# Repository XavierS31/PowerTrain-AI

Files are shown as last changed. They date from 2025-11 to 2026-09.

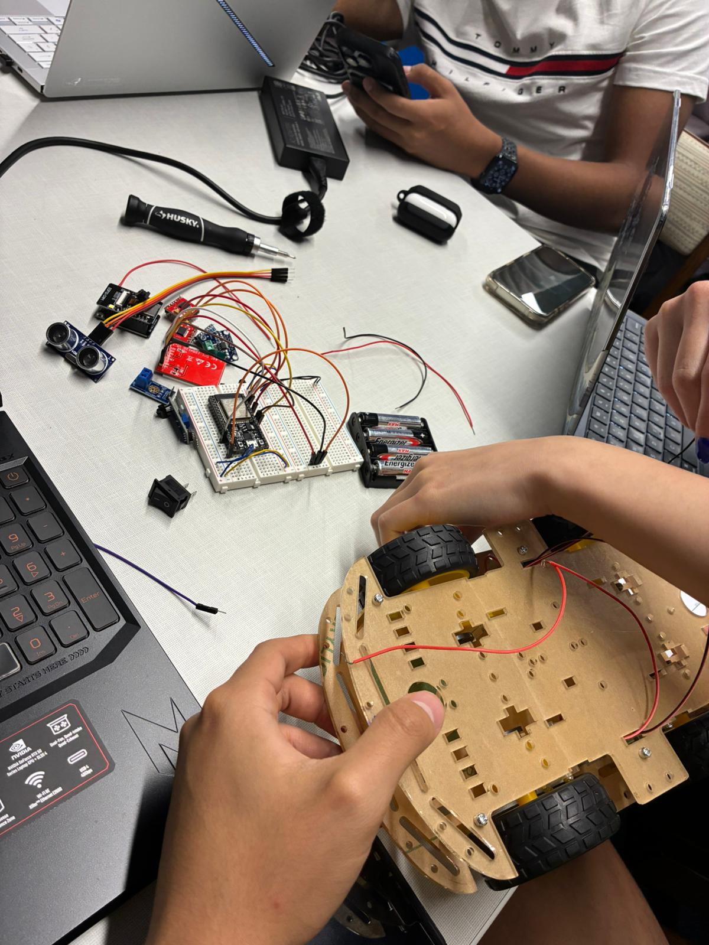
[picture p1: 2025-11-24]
images/buildingBeginning.jpg

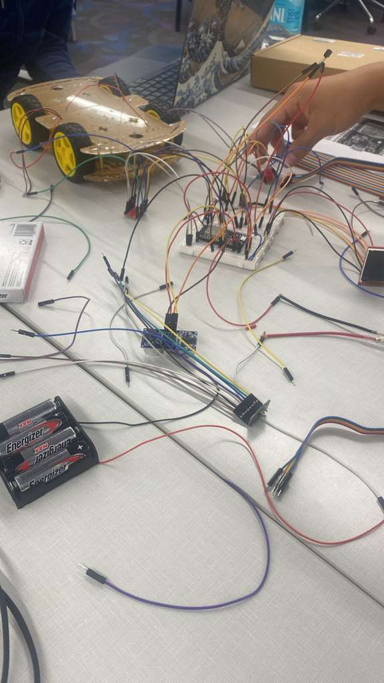
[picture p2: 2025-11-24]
images/circuitBuilding.jpg

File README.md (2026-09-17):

# ⚡ PowerTrain AI

PowerTrain AI is a comprehensive autonomous car system powered by ESP32, featuring real-time sensor data collection, machine learning-based performance prediction, and intelligent autonomous driving capabilities. The system integrates embedded hardware, Python-based ML models, and RESTful APIs to create a complete end-to-end solution for autonomous vehicle control and battery health monitoring.

## 🚀 Overview

PowerTrain AI combines embedded systems engineering with machine learning to create an intelligent autonomous car that adapts its driving behavior based on real-time performance predictions. The system collects sensor data from multiple sources (temperature, voltage, current, acceleration, distance), processes it through ML models which are later tested, and uses predictions to optimize autonomous driving decisions in real-time.

The project consists of three main components:
- **Embedded System**: ESP32-based car with sensor integration and autonomous driving logic
- **Machine Learning**: Tested Three ML models (PyTorch Neural Network, scikit-learn MLP, Random Forest Algortihm) for performance prediction and pick the best results.
- **Data Infrastructure**: Flask servers for data collection, ML predictions, and database management

## ⚙️ Features

### 🚗 Autonomous Driving

- **Basic Autonomous Mode**: Obstacle avoidance using ultrasonic (HC-SR04) and infrared sensors
- **ML-Enhanced Autonomous Mode**: Performance-based speed and behavior adjustment using real-time ML predictions
- **Three Speed Levels**: Low (85 PWM), Medium (170 PWM), High (255 PWM) with smooth acceleration/deceleration
- **Intelligent Navigation**: Left/right path selection based on obstacle detection and distance scanning
- **Emergency Stop**: Immediate stop on critical obstacle detection

### 📊 Sensor Data Collection

- **Temperature Monitoring**: DS18B20 digital temperature sensor (OneWire protocol)
- **Voltage Detection**: 0-25V voltage sensor module (GPIO 34 ADC)
- **Current/Power Measurement**: INA219 I2C sensor for precise current and power readings
- **Accelerometer/Gyroscope**: MPU6050 6-axis IMU (I2C) for acceleration and orientation
- **Distance Sensing**: HC-SR04 ultrasonic sensor (GPIO 17/16) for obstacle detection
- **Infrared Obstacle Detection**: TCRT5000 IR sensor (GPIO 36/39) for close-range detection
- **Speed Measurement**: Encoder-based speed calculation from motor rotations

### 🧠 Machine Learning Models Tested

#### PyTorch Neural Network
- **Architecture**: 2 hidden layers with 16 neurons each
- **Activation**: ReLU with Dropout (0.2) for regularization
- **Framework**: PyTorch
- **Output**: Performance level classification (1-10)
- **Saved as**: `pytorch_nn_model.pth`

#### scikit-learn MLP (Multi-Layer Perceptron)
- **Architecture**: 2 hidden layers (16, 8 neurons)
- **Framework**: scikit-learn
- **Solver**: Adam optimizer
- **Output**: Performance level classification (1-10)
- **Saved as**: `mlp_model.py`

#### Random Forest Classifier
- **Parameters**: 100 decision trees, max depth 20
- **Framework**: scikit-learn
- **Features**: Feature importance analysis
- **Output**: Performance level classification (1-10)
- **Saved as**: `random_forest_model.py`

### 📡 Data Infrastructure

- **Data Receiver API**: Flask server receiving sensor data from ESP32 via WiFi
- **ML Prediction API**: Real-time performance predictions from trained models
- **Data Query API**: RESTful API for querying SQLite database
- **Multiple Data Formats**: JSON, CSV, SQLite, Parquet, HDF5, Excel support
- **SQLite Database**: Structured storage for driving behavior data with indexes

### 🖥️ TFT Display

- **ST7735S Display**: 1.8" TFT screen showing real-time performance metrics
- **Performance Percentage**: Calculated from internal resistance, temperature, and current
- **Visual Feedback**: Color-coded performance indicators

## 🧑‍💻 Tech Stack

| Layer | Technologies |
|---|---|
| **Embedded** | ESP32 DevKit V1, Arduino Framework, PlatformIO, C++, C|
| **Sensors** | DS18B20, INA219, MPU6050, HC-SR04, TCRT5000, Voltage Sensor |
| **Actuators** | TB6612FNG Motor Driver, ST7735S TFT Display |
| **Communication** | WiFi (HTTP), Bluetooth (optional), Serial (115200 baud) |
| **Backend** | Python, Flask, SQLite |
| **Machine Learning** | PyTorch, scikit-learn, NumPy, Pandas, Matplotlib |
| **Data Processing** | Pandas, NumPy, StandardScaler |
| **Visualization** | Matplotlib, Seaborn |
| **Development** | PlatformIO, Arduino IDE compatible |

## 🛠️ Setup Instructions

### Prerequisites

- **Python** (for ML models and data servers)
- **Node.js** (optional, for some utilities)
- **PlatformIO** or **Arduino IDE** (for ESP32 development)
- **ESP32 DevKit V1** connected via USB
- **Git**

### 1. Clone the Repository

```bash
git clone https://github.com/XavierS31/PowerTrain-AI.git
cd PowerTrain-AI
```

### 2. Python Environment Setup

```bash
# Install Python dependencies
cd Software
pip install -r requirements.txt
```

Required packages:
- `pandas`, `numpy`, `scikit-learn`, `torch` (PyTorch)
- `flask`, `flask-cors`, `python-dotenv`
- `matplotlib`, `seaborn`, `joblib`
- `sqlite3` (built-in)

### 3. Database Setup

```bash
cd Software/src
python create_database.py
```

This creates:
- SQLite database at `Software/data/database/driving_behavior.db`
- Schema with indexes for performance
- Imports data from `driving_behavior_dataset.csv` (if available)

### 4. Train Machine Learning Models

Train all three models at once:

```bash
cd Software/src
python save_model.py
```

Or train individually:

```bash
# PyTorch Neural Network
python train_pytorch_nn.py

# scikit-learn MLP
python train_mlp.py

# Random Forest
python train_random_forest.py
```

Models are saved to `Software/models/`:
- `pytorch_nn_model.pth` + `pytorch_scaler.joblib`
- `mlp_model.joblib` + `scaler.joblib`
- `random_forest_model.joblib` + `random_forest_scaler.joblib`

### 5. Evaluate Models

Compare all trained models:

```bash
cd Software/src
python evaluate_models.py
```

Generates:
- Confusion matrices for each model
- Model comparison plots
- Comprehensive evaluation report with accuracy, precision, recall, F1-score

### 6. Configure ESP32

Edit `Embedded/src/config/config.h`:

```cpp
#define WIFI_SSID "YOUR_WIFI_SSID"
#define WIFI_PASSWORD "YOUR_WIFI_PASSWORD"
#define SERVER_IP "OUR_IP"  // Your computer's IP
#define SERVER_PORT 5000
```

Or use the template: `Embedded/src/config/config.h.template`

### 7. Compile and Upload to ESP32

#### Option A: Using Batch Script (Windows)

```bash
cd Embedded
compile_and_upload_autonomous.bat
```

This script:
1. Compiles code with PlatformIO
2. Prompts for ESP32 upload
3. Handles download mode instructions

**If upload fails:**
1. Hold the **BOOT** button
2. Press and release **RESET** button
3. Release **BOOT** button
4. Try upload again

#### Option B: Using PlatformIO CLI

```bash
cd Embedded
pio run              # Compile
pio run -t upload    # Upload
pio device monitor    # Serial monitor
```

#### Option C: Using Arduino IDE

1. Open `Embedded/autonomous_Driving/autonomous_Driving.ino` in Arduino IDE
2. Install ESP32 board support (ESP32 Dev Module)
3. Install required libraries:
   - NewPing
   - Encoder
   - OneWire
   - DallasTemperature
   - Adafruit INA219
   - Adafruit MPU6050
   - Adafruit ST7735
   - Adafruit GFX
4. Select board: **ESP32 Dev Module**
5. Select port: **COM4** (or your port)
6. Upload

### 8. Start Data Receiver Server

```bash
cd Software/data
python data_receiver.py
```

Server runs on `http://0.0.0.0:5000` (configurable via `.env`)

Endpoints:
- `POST /api/data` - Receive sensor data from ESP32
- `POST /api/predict` - Get ML prediction for sensor data
- `GET /api/status` - Check server and model status

### 9. Start Data Query API (Optional)

```bash
cd Software/data
python data_api.py
```

API runs on `http://0.0.0.0:5001` (configurable via `DATA_API_PORT` in `.env`)

Endpoints:
- `GET /api/data/records` - Query driving behavior records
- `GET /api/data/stats` - Statistical summary
- `GET /api/data/levels` - Level distribution
- `GET /api/data/record/<id>` - Get specific record
- `GET /api/data/export` - Export as CSV
- `GET /api/data/status` - API health check

## 📡 API Documentation

### Data Receiver API (Port 5000)

#### POST /api/data
Receive sensor data from ESP32 and save to database.

**Request Body:**
```json
{
  "temperature": 25.5,
  "voltage": 12.3,
  "current": 1.2,
  "power": 14.76,
  "accelX": 0.1,
  "accelY": 0.2,
  "accelZ": 9.8,
  "gyroX": 0.0,
  "gyroY": 0.0,
  "gyroZ": 0.0,
  "distance": 45.0,
  "speed": 0.5,
  "irDigital": 0,
  "irAnalog": 512
}
```

**Response:**
```json
{
  "status": "success",
  "message": "Data saved"
}
```

#### POST /api/predict
Get ML prediction for sensor data.

**Request Body:**
```json
{
  "voltage": 12.3,
  "current": 1.2,
  "temperature": 25.5,
  "accelX": 0.1,
  "accelY": 0.2,
  "accelZ": 9.8,
  "speed": 0.5,
  "distance": 45.0
}
```

**Response:**
```json
{
  "status": "success",
  "predicted_level": 7,
  "confidence": 0.92
}
```

#### GET /api/status
Check server and model status.

**Response:**
```json
{
  "status": "running",
  "model_loaded": true,
  "scaler_loaded": true
}
```

### Data Query API (Port 5001)

#### GET /api/data/records
Query driving behavior records with filtering.

**Query Parameters:**
- `limit` (default: 100) - Number of records
- `offset` (default: 0) - Pagination offset
- `level` - Filter by performance level (1-10)
- `min_voltage` - Minimum voltage filter
- `max_voltage` - Maximum voltage filter

**Example:**
```
GET /api/data/records?limit=50&level=7&min_voltage=12.0
```

#### GET /api/data/stats
Get statistical summary of database.

**Response:**
```json
{
  "total_records": 1000,
  "levels": {
    "1": 50,
    "2": 75,
    ...
  },
  "avg_voltage": 12.3,
  "avg_current": 1.2
}
```

## 📁 Project Structure

```
PowerTrain AI/
├── Embedded/                          # ESP32 firmware
│   ├── src/
│   │   ├── main.cpp                  # Main program entry point
│   │   ├── ESP32_car.h               # Core library includes
│   │   ├── config/
│   │   │   ├── config.h             # Configuration (WiFi, pins, speeds)
│   │   │   └── config.h.template    # Configuration template
│   │   ├── sensors/
│   │   │   ├── DS18B20_temp.cpp     # Temperature sensor driver
│   │   │   ├── HC-SRO4_Infrared.cpp # Ultrasonic distance sensor
│   │   │   ├── I2C_BUS.cpp          # I2C bus initialization
│   │   │   ├── IR_MH_Sensor.cpp     # Infrared obstacle sensor
│   │   │   ├── TB6612FNG_MotorStepper.cpp  # Motor driver
│   │   │   ├── TFT_LED.cpp          # TFT display functions
│   │   │   ├── TFT_LED.h            # TFT display header
│   │   │   └── voltage_sensor.cpp   # Voltage detection
│   │   ├── autonomous_drive.h       # Basic autonomous driving header
│   │   ├── autonomous_drive_ml.h    # ML-enhanced driving header
│   │   ├── autonomous_drive_ml.cpp  # ML-enhanced driving implementation
│   │   ├── ml_predictor.h           # ML prediction API header
│   │   └── ml_predictor.cpp         # HTTP client for ML predictions
│   ├── autonomous_Driving/
│   │   └── autonomous_Driving.ino   # Standalone autonomous sketch
│   ├── bluetooth_Driving/
│   │   └── bluetooth_Driving.ino    # Bluetooth control sketch
│   ├── compile_and_upload_autonomous.bat  # Build and upload script
│   └── platformio.ini               # PlatformIO configuration
│
├── Software/                         # Python ML and data processing
│   ├── data/
│   │   ├── raw_data/                # Raw sensor data from ESP32
│   │   │   └── *.jsonl, *.csv, *.db, *.parquet, *.h5, *.xlsx
│   │   ├── database/
│   │   │   └── driving_behavior.db   # SQLite database
│   │   ├── data_receiver.py         # Flask server for data reception
│   │   ├── data_api.py              # RESTful API for data queries
│   │   ├── check_security.py        # Security scanner
│   │   ├── SECURITY.md              # Security guidelines
│   │   ├── driving_behavior_dataset.csv  # Training dataset
│   │   └── data.pdf                 # Data documentation
│   ├── models/                      # Trained ML models
│   │   ├── mlp_model.joblib        # scikit-learn MLP model
│   │   ├── scaler.joblib           # Feature scaler for MLP
│   │   ├── random_forest_model.joblib
│   │   ├── random_forest_scaler.joblib
│   │   ├── pytorch_nn_model.pth    # PyTorch neural network
│   │   ├── pytorch_scaler.joblib
│   │   └── results/                # Evaluation plots and reports
│   ├── src/
│   │   ├── create_database.py      # Create SQLite database from CSV
│   │   ├── preprocessing.py          # Process raw data for ML
│   │   ├── save_model.py            # Train and save all three models
│   │   ├── train_pytorch_nn.py      # Train PyTorch neural network
│   │   ├── train_random_forest.py   # Train Random Forest
│   │   ├── train_mlp.py            # Train scikit-learn MLP
│   │   ├── evaluate_models.py       # Evaluate all models
│   │   └── model.py                # Original MLP training script
│   ├── requirements.txt             # Python dependencies
│   └── README.md                    # Software module documentation
│
├── scripts/                         # Utility scripts
│   ├── install_platformio.ps1      # PlatformIO installation (Windows)
│   └── install_platformio.sh       # PlatformIO installation (Linux/Mac)
│
├── images/                          # Project images
│   ├── car.jpg
│   ├── carSideways.jpg
│   ├── carTraining.jpg
│   ├── buildingBeginning.jpg
│   └── circuitBuilding.jpg
│
├── Modelling/                       # 3D models
│   ├── base_modelling_final.SLDPRT
│   ├── base_modelling_intial.SLDPRT
│   └── solidworks_Final.jpg
│
├── Schematics/                      # Circuit schematics
│   ├── Schematics.jpg
│   └── Schematics_start.jpg
│
├── run_model.bat                    # Run ML model training
├── .gitignore                       # Git ignore rules
├── PLATFORMIO_SETUP.md              # PlatformIO setup guide
└── README.md                        # This file
```

## 🔄 Data Flow

### Training Phase

1. **Data Collection**: ESP32 collects sensor data during autonomous driving
2. **Data Transmission**: Sensor data sent via WiFi to Flask server (`data_receiver.py`)
3. **Data Storage**: Data saved in multiple formats (CSV, JSON, SQLite, etc.)
4. **Data Preprocessing**: `preprocessing.py` calculates derived features:
   - Internal resistance (from voltage drop and current)
   - Combined acceleration magnitude
   - Cumulative distance
   - Performance level assignment (1-10)
5. **Database Import**: `create_database.py` imports processed data to SQLite
6. **Model Training**: `save_model.py` trains all three models:
   - Features: InternalResistance, StartingInternalResistance, Voltage, Current, Temp, AccelX, AccelY, AccelCombined, Speed, Distance
   - Target: Level (1-10 performance classification)
   - Train-test split: 80-20 with stratification
   - Feature scaling: StandardScaler
7. **Model Evaluation**: `evaluate_models.py` compares all models and generates reports

### Inference Phase (Real-Time)

1. **Sensor Reading**: ESP32 reads all sensors (temperature, voltage, current, acceleration, distance, speed)
2. **Data Preprocessing**: ESP32 calculates internal resistance and combined acceleration
3. **HTTP Request**: ESP32 sends sensor data to `/api/predict` endpoint
4. **ML Prediction**: Python server:
   - Loads trained model and scaler
   - Preprocesses input data
   - Makes prediction (level 1-10)
   - Returns prediction and confidence
5. **Autonomous Decision**: ESP32 uses prediction to:
   - Adjust speed based on performance level
   - Modify obstacle detection thresholds
   - Optimize driving behavior

## 🎯 Autonomous Driving Modes

### Basic Autonomous Mode

Uses sensor-based obstacle avoidance:
- Forward movement with continuous distance monitoring
- Turn left/right based on clearer path detection
- Backup and turn when completely blocked
- Speed control via Serial commands (L/M/H/S)

### ML-Enhanced Autonomous Mode

Integrates ML predictions for intelligent behavior:
- **Performance-Based Speed**: Adjusts speed based on predicted performance level
  - Level 1-3: Low speed (conservative)
  - Level 4-7: Medium speed (balanced)
  - Level 8-10: High speed (aggressive)
- **Adaptive Thresholds**: Obstacle detection thresholds adjust based on confidence
- **Predictive Behavior**: Anticipates performance degradation and adjusts proactively

## 📊 Model Training Results

All models are trained on the same dataset with:
- **Features**: 10 input features (InternalResistance, Voltage, Current, Temp, AccelX, AccelY, AccelCombined, Speed, Distance, StartingInternalResistance)
- **Target**: Performance level (1-10 classification)
- **Train-Test Split**: 80-20 with stratification
- **Evaluation Metrics**: Accuracy, Precision, Recall, F1-Score, Confusion Matrix

Run `evaluate_models.py` to see detailed results for each model.

## 🚀 Running Batch Scripts

### run_model.bat

Trains the MLP model and generates visualization:

```bash
run_model.bat
```

This script:
1. Checks Python installation
2. Installs required packages
3. Runs `train_mlp.py`
4. Generates confusion matrix visualization
5. Saves results to `Software/models/results/`

### compile_and_upload_autonomous.bat

Compiles and uploads autonomous driving code to ESP32:

```bash
cd Embedded
compile_and_upload_autonomous.bat
```

This script:
1. Compiles code with PlatformIO
2. Prompts for ESP32 upload
3. Provides instructions for download mode if needed

**Note**: Make sure ESP32 is connected to COM4 (or update `platformio.ini` with your port).

## 🔧 Troubleshooting

### ESP32 Upload Issues

**Problem**: Upload fails with "Wrong boot mode detected"

**Solution**:
1. Hold the **BOOT** button
2. Press and release **RESET** button
3. Release **BOOT** button
4. Try upload again within 10 seconds

### WiFi Connection Issues

**Problem**: ESP32 cannot connect to WiFi

**Solution**:
1. Check WiFi credentials in `Embedded/src/config/config.h`
2. Verify WiFi network is 2.4GHz (ESP32 doesn't support 5GHz)
3. Check signal strength
4. Review Serial monitor for connection errors

### ML Predictions Not Working

**Problem**: ESP32 cannot get predictions from server

**Solution**:
1. Ensure `data_receiver.py` is running on port 5000
2. Check server IP in `config.h` matches your computer's IP
3. Verify models are loaded (check `/api/status` endpoint)
4. Check firewall settings allow port 5000

### Database Not Found

**Problem**: Models cannot find database

**Solution**:
```bash
cd Software/src
python create_database.py
```

### Model Training Errors

**Problem**: Training fails with missing data

**Solution**:
1. Ensure database exists: `Software/data/database/driving_behavior.db`
2. Verify database has data: Check with SQLite browser
3. Run `create_database.py` to import CSV data

### Sensor Reading Issues

**Problem**: Sensors not reading correctly

**Solution**:
1. Verify I2C connections (SDA=21, SCL=22)
2. Check sensor addresses with I2C scanner
3. Verify power supply (3.3V for sensors)
4. Check GPIO pin assignments in `config.h`

## Support

For questions, issues, or contributions:

- **Repository**: [PowerTrain AI](https://github.com/XavierS31/PowerTrain-AI)
- **Issues**: Open an issue on GitHub

## 🎯 Future Enhancements

- Real-time model retraining with new data
- Advanced sensor fusion algorithms
- Computer vision integration for object recognition
- GPS-based navigation and path planning
- Mobile app for remote monitoring and control
- Cloud deployment for ML inference
- Enhanced battery health prediction
- Multi-car fleet management
- Advanced obstacle avoidance with LiDAR
- Reinforcement learning for adaptive behavior

## 📝 License

This project is open source and available for educational and research purposes.

## 🙏 Acknowledgments

- ESP32 community for excellent documentation
- PlatformIO for seamless embedded development
- PyTorch and scikit-learn teams for ML frameworks
- Adafruit for sensor libraries and hardware

---

**Built with passion for autonomous systems and machine learning** ⚡🚗

**Resulted in first place for SHPE FALL 2025 Competitions**

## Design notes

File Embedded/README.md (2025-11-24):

# PowerTrain AI - Embedded Module

ESP32-based autonomous car with sensor integration and ML-powered performance prediction.

## Project Structure

```
Embedded/
├── src/
│   ├── main.cpp                    # Main program entry point
│   ├── ESP32_car.h                # Core library includes
│   ├── config/
│   │   └── config.h               # Configuration constants
│   ├── sensors/
│   │   ├── DS18B20_temp.cpp       # Temperature sensor
│   │   ├── HC-SRO4_Infrared.cpp   # Ultrasonic distance sensor
│   │   ├── I2C_BUS.cpp            # I2C bus initialization
│   │   ├── IR_MH_Sensor.cpp       # Infrared obstacle sensor
│   │   ├── TB6612FNG_MotorStepper.cpp  # Motor driver
│   │   ├── TFT_LED.cpp            # TFT display functions
│   │   ├── TFT_LED.h             # TFT display header
│   │   └── voltage_sensor.cpp    # Voltage detection
│   ├── autonomous_drive.h         # Autonomous driving header
│   ├── autonomous_drive_ml.h      # ML-enhanced driving header
│   ├── autonomous_drive_ml.cpp    # ML-enhanced driving implementation
│   ├── ml_predictor.h             # ML prediction API header
│   └── ml_predictor.cpp           # ML prediction API implementation
│
├── autonomous_Driving/
│   └── autonomous_Driving.ino     # Standalone autonomous driving sketch
│
├── bluetooth_Driving/
│   └── bluetooth_Driving.ino      # Bluetooth control sketch
│
├── compile_and_upload_autonomous.bat  # Build and upload script
└── platformio.ini                 # PlatformIO configuration
```

## Core Files

### Main Entry Point
- `src/main.cpp` - Main program loop, initializes sensors and runs autonomous driving

### Configuration
- `src/config/config.h` - Pin definitions, thresholds, timing constants

### Sensor Drivers
- `src/sensors/DS18B20_temp.cpp` - DS18B20 temperature sensor driver
- `src/sensors/HC-SRO4_Infrared.cpp` - HC-SR04 ultrasonic distance sensor
- `src/sensors/IR_MH_Sensor.cpp` - Infrared obstacle detection
- `src/sensors/voltage_sensor.cpp` - Battery voltage monitoring
- `src/sensors/TB6612FNG_MotorStepper.cpp` - Motor control driver
- `src/sensors/TFT_LED.cpp` - ST7735S TFT display driver
- `src/sensors/I2C_BUS.cpp` - I2C bus setup for sensors

### Autonomous Driving
- `src/autonomous_drive.h` - Basic autonomous driving interface
- `src/autonomous_drive_ml.h` - ML-enhanced autonomous driving interface
- `src/autonomous_drive_ml.cpp` - ML-enhanced driving with performance-based adjustments

### Machine Learning Integration
- `src/ml_predictor.h` - ML prediction API interface
- `src/ml_predictor.cpp` - HTTP client for Python ML server predictions

### Library Includes
- `src/ESP32_car.h` - Central header with all required library includes

## Compilation and Upload

### Using Batch Script

```bash
cd Embedded
compile_and_upload_autonomous.bat
```

This script:
1. Copies autonomous code to main.cpp
2. Compiles with PlatformIO
3. Prompts for ESP32 upload

### Using PlatformIO Directly

```bash
cd Embedded
pio run -t upload
```

## Hardware Configuration

### Sensors
- Temperature: DS18B20 (OneWire)
- Voltage: 0-25V detection module (GPIO 34)
- Current/Power: INA219 (I2C)
- Accelerometer/Gyro: MPU6050 (I2C)
- Distance: HC-SR04 (GPIO 17 trigger, GPIO 16 echo)
- Infrared: TCRT5000 (GPIO 36 digital, GPIO 39 analog)

### Actuators
- Motors: TB6612FNG driver (PWM control)
- Display: ST7735S TFT (SPI)

### Communication
- WiFi: For data transmission and ML predictions
- Serial: Debug output (115200 baud)

## Autonomous Driving Modes

### Basic Autonomous Mode
Uses obstacle avoidance with ultrasonic and IR sensors:
- Forward movement with obstacle detection
- Turn left/right based on clearer path
- Backup and turn when blocked

### ML-Enhanced Autonomous Mode
Integrates ML predictions to adjust behavior:
- Speed adjustment based on predicted performance level
- Obstacle threshold adaptation
- Confidence-based decision making

## ML Prediction Integration

The car can request performance predictions from the Python server:

```cpp
#include "src/ml_predictor.h"

SensorData data = readSensors();
MLPrediction pred = getMLPrediction(data, "http://SERVER_IP:5000");

if (pred.success) {
    // Use pred.level (1-10) and pred.confidence (0.0-1.0)
    adjustBehavior(pred);
}
```

## Key Functions

### Sensor Reading
- `readSensors()` - Read all sensor values
- `readDistance()` - Get ultrasonic distance
- `readIRSensor()` - Check IR obstacle detection
- `checkLeftDistance()` - Scan left side
- `checkRightDistance()` - Scan right side

### Motor Control
- `driveForward(speed)` - Move forward
- `turnLeft(speed)` - Turn left
- `turnRight(speed)` - Turn right
- `driveBackward(speed)` - Reverse
- `stopMotors()` - Stop all motors
- `emergencyStop()` - Immediate stop

### Autonomous Driving
- `autonomousDrive()` - Basic autonomous mode
- `autonomousDriveML()` - ML-enhanced autonomous mode
- `initAutonomousDrive()` - Initialize autonomous system
- `initAutonomousDriveML()` - Initialize ML-enhanced system

### ML Predictions
- `getMLPrediction(sensorData, serverURL)` - Get prediction from server
- `checkMLModelStatus(serverURL)` - Check if ML model is loaded

## Configuration

Edit `src/config/config.h` to adjust:
- Pin assignments
- Motor speeds
- Obstacle detection thresholds
- Sensor calibration values
- WiFi credentials
- Server URL

## Dependencies

PlatformIO libraries (defined in platformio.ini):
- OneWire
- DallasTemperature
- Adafruit INA219
- Adafruit MPU6050
- NewPing
- Adafruit ST7735
- Adafruit GFX
- Encoder
- ESP32AnalogRead
- ArduinoJson
- HTTPClient

## Development Workflow

1. Edit source files in `src/`
2. Update configuration in `src/config/config.h`
3. Compile: `pio run`
4. Upload: `pio run -t upload`
5. Monitor: `pio device monitor`

## Troubleshooting

- Upload fails: Put ESP32 in download mode (hold BOOT, press RESET, release BOOT)
- WiFi not connecting: Check credentials in config.h
- Sensors not reading: Verify I2C connections and addresses
- Motors not moving: Check motor driver connections and PWM pins
- ML predictions fail: Ensure Python server is running and accessible

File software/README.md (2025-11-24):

# PowerTrain AI - Software Module

Machine learning system for predicting performance levels from ESP32 sensor data.

## Project Structure

```
Software/
├── data/
│   ├── raw_data/              # Raw sensor data from ESP32
│   │   └── driving_behavior_dataset.csv
│   ├── processed/             # Preprocessed data ready for ML
│   ├── database/              # SQLite database
│   │   └── driving_behavior.db
│   └── data_receiver.py       # Flask server to receive ESP32 data
│
├── models/                    # Trained models and results
│   ├── mlp_model.joblib      # MLP (sklearn) model
│   ├── scaler.joblib         # Feature scaler for MLP
│   ├── random_forest_model.joblib
│   ├── random_forest_scaler.joblib
│   ├── pytorch_nn_model.pth  # PyTorch neural network
│   ├── pytorch_scaler.joblib
│   └── results/               # Evaluation plots and reports
│
└── src/
    ├── create_database.py     # Create SQLite database from CSV
    ├── preprocessing.py       # Process raw data for ML training
    ├── save_model.py          # Train and save all three models
    ├── train_pytorch_nn.py    # Train PyTorch neural network
    ├── train_random_forest.py # Train Random Forest
    ├── train_mlp.py           # Train MLP (sklearn)
    ├── model.py               # Original MLP training script
    └── evaluate_models.py    # Evaluate all models
```

## Installation

Install required dependencies:

```bash
pip install pandas numpy scikit-learn torch matplotlib seaborn joblib flask python-dotenv
```

## Database Setup

1. Create SQLite database and import data:

```bash
cd Software/src
python create_database.py
```

This creates `Software/data/database/driving_behavior.db` with the schema and imports data from CSV.

## Model Training

### Train All Models

Train all three models (MLP, PyTorch NN, Random Forest) at once:

```bash
cd Software/src
python save_model.py
```

### Train Individual Models

Train models individually:

```bash
# MLP (sklearn)
python train_mlp.py

# PyTorch Neural Network
python train_pytorch_nn.py

# Random Forest
python train_random_forest.py
```

All models read from the SQLite database at `Software/data/database/driving_behavior.db`.

## Model Evaluation

Evaluate all trained models and compare performance:

```bash
cd Software/src
python evaluate_models.py
```

This generates:
- Confusion matrices for each model
- Model comparison plots
- Comprehensive evaluation report

## Data Preprocessing

Process raw sensor data for ML training:

```bash
cd Software/src
python preprocessing.py --input sensor_data.csv --format csv
```

## Data Receiver Server

Start the Flask server to receive sensor data from ESP32:

```bash
cd Software/data
python data_receiver.py
```

The server provides:
- `/api/data` - POST endpoint to receive sensor data
- `/api/predict` - POST endpoint for ML predictions
- `/api/status` - GET endpoint to check server status

## Models

### MLP (sklearn)
- Architecture: 2 hidden layers (16, 8 neurons)
- Framework: scikit-learn
- Saved as: `mlp_model.joblib`

### PyTorch Neural Network
- Architecture: 2 hidden layers, 16 neurons each
- Framework: PyTorch
- Saved as: `pytorch_nn_model.pth`

### Random Forest
- Parameters: 100 trees, max depth 20
- Framework: scikit-learn
- Saved as: `random_forest_model.joblib`

## Data Format

All models expect the same input features:
- InternalResistance
- StartingInternalResistance
- Voltage
- Current
- Temp
- AccelX
- AccelY
- AccelCombined
- Speed
- Distance

Target: Level (1-10 performance classification)

## Workflow

1. **Setup Database:**
   ```bash
   python create_database.py
   ```

2. **Train Models:**
   ```bash
   python save_model.py
   ```

3. **Evaluate Models:**
   ```bash
   python evaluate_models.py
   ```

4. **Start Data Receiver:**
   ```bash
   cd ../data
   python data_receiver.py
   ```

5. **Use Predictions:**
   - ESP32 sends sensor data to `/api/data`
   - ESP32 requests predictions from `/api/predict`
   - Server returns predicted performance level (1-10)

## File Descriptions

- `create_database.py` - Creates SQLite schema and imports CSV data
- `preprocessing.py` - Processes raw sensor data into ML-ready format
- `save_model.py` - Trains and saves all three ML models
- `train_pytorch_nn.py` - PyTorch neural network training
- `train_random_forest.py` - Random Forest training
- `train_mlp.py` - MLP (sklearn) training
- `evaluate_models.py` - Comprehensive model evaluation and comparison
- `data_receiver.py` - Flask server for receiving data and providing predictions

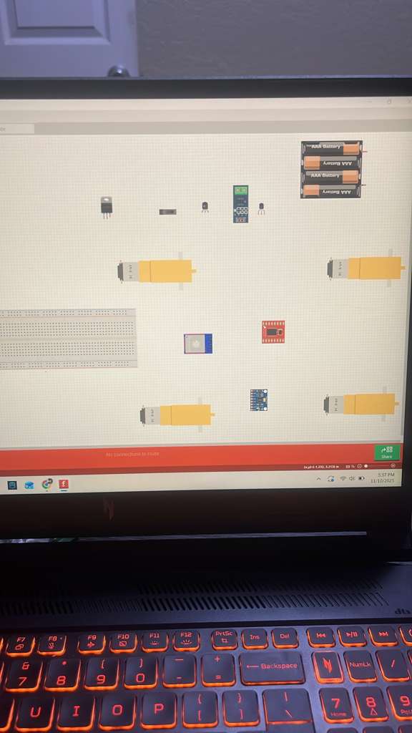
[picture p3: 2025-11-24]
Schematics/Schematics_start.jpg

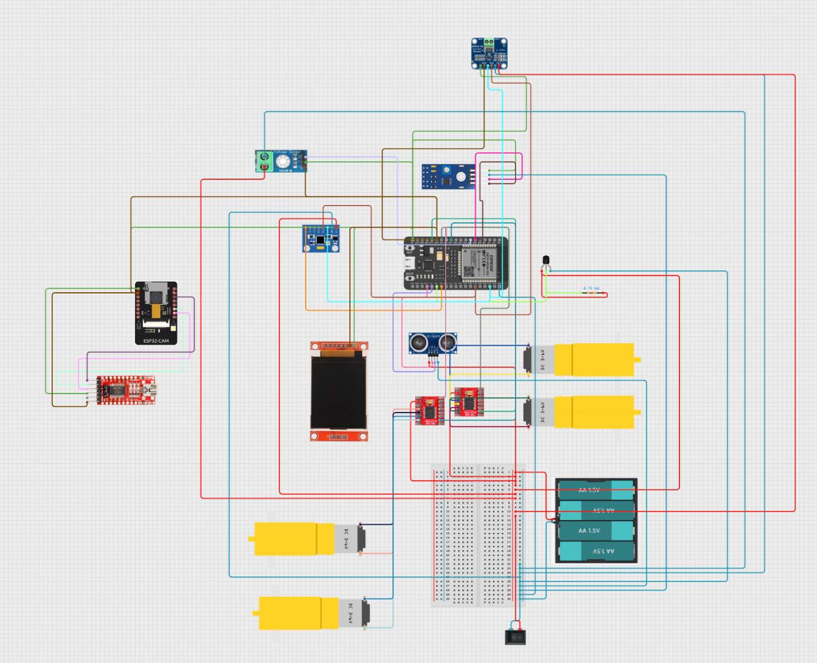
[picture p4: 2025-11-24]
Schematics/Schematics.jpg

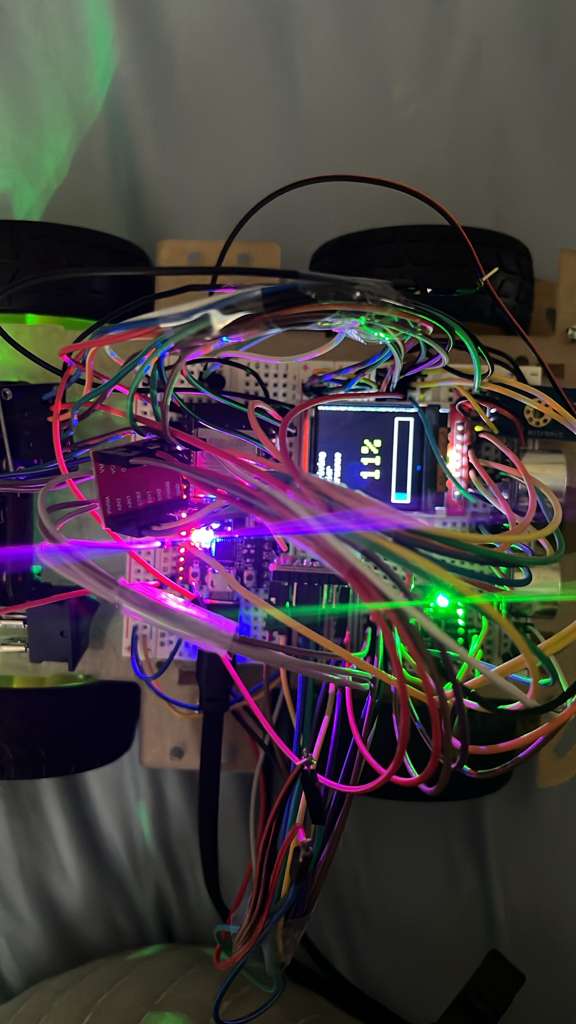
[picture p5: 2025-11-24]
images/carTraining.jpg

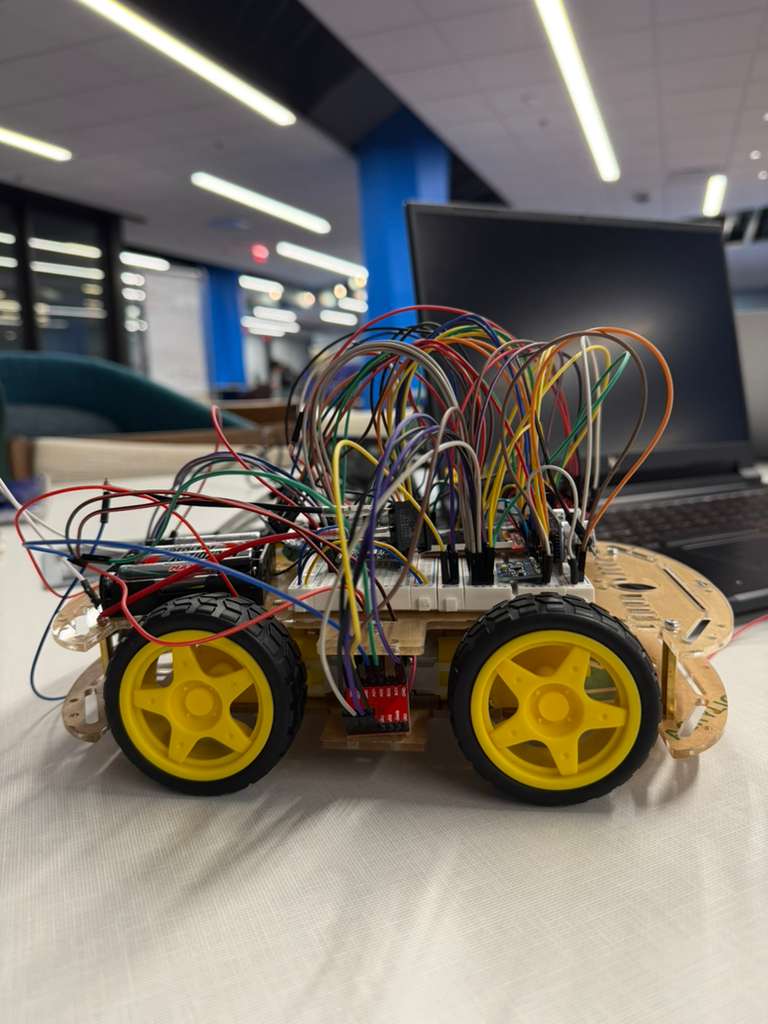
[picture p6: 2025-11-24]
images/carSideways.jpg

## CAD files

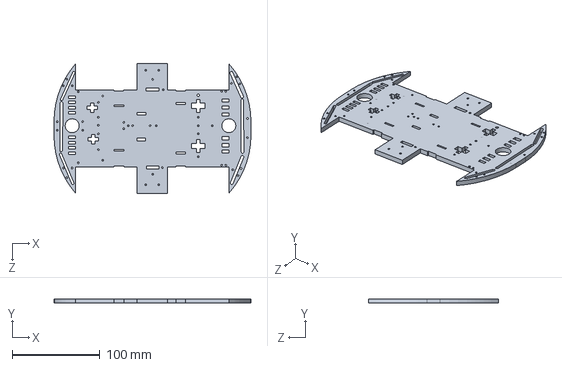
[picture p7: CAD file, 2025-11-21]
Modelling/base_modelling_final.SLDPRT
225.0 x 5.00 x 148.0 mm

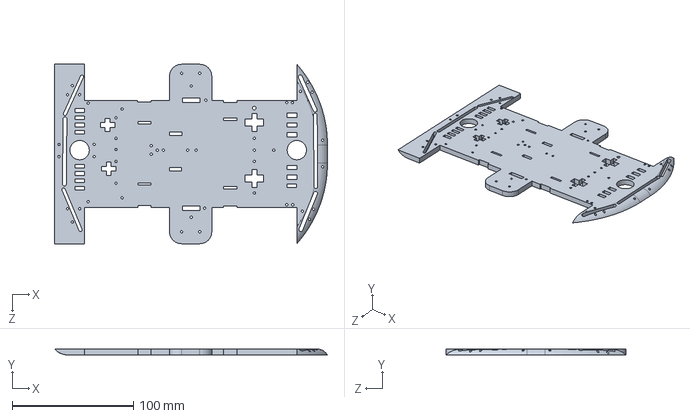
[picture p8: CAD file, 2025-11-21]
Modelling/base_modelling_intial.SLDPRT
225.0 x 5.00 x 148.0 mm

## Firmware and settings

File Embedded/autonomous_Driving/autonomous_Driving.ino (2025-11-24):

/*
 * Pure Autonomous Driving - Standalone Version
 * 
 * This is a minimal implementation focused ONLY on autonomous driving.
 * No data logging, no WiFi, no TFT display updates.
 * Just pure obstacle avoidance and navigation.
 * 
 * Usage:
 * 1. Upload this to ESP32
 * 2. Car will start driving autonomously immediately
 * 3. Use Serial commands to control speed: L/M/H/S (Low/Medium/High/Stop)
 */

#include <Arduino.h>
#include <NewPing.h>
#include <Encoder.h>

// Motor Control
#define MOTOR_STBY 27
#define MOTOR_PWMA 25
#define MOTOR_AIN1 26
#define MOTOR_AIN2 13

// Speed Levels
#define SPEED_LOW 85
#define SPEED_MEDIUM 170
#define SPEED_HIGH 255

#define MIN_MOTOR_SPEED 50
const int PWMFreq = 20000;
const int PWMResolution = 8;
const int motorPWMSpeedChannel = 4;

int currentSpeed = SPEED_MEDIUM;
int currentRightSpeed = 0;
int currentLeftSpeed = 0;

// Sensor Pins
#define HC_TRIG 17
#define HC_ECHO 16
#define IR_DO 36
#define IR_AO 39

// Obstacle Detection
NewPing sonar(HC_TRIG, HC_ECHO, 200);
#define OBSTACLE_DISTANCE 30
#define TURN_DURATION 500
#define SAFE_DISTANCE 40
#define CRITICAL_DISTANCE 20

// Motor Control Functions
void applyAcceleration(int targetRightSpeed, int targetLeftSpeed) {
  const int ACCEL_STEP = 5;
  const int DECEL_STEP = 8;
  
  if (targetRightSpeed > currentRightSpeed) {
    currentRightSpeed += ACCEL_STEP;
    if (currentRightSpeed > targetRightSpeed) currentRightSpeed = targetRightSpeed;
  } else if (targetRightSpeed < currentRightSpeed) {
    currentRightSpeed -= DECEL_STEP;
    if (currentRightSpeed < targetRightSpeed) currentRightSpeed = targetRightSpeed;
  }
  
  if (targetLeftSpeed > currentLeftSpeed) {
    currentLeftSpeed += ACCEL_STEP;
    if (currentLeftSpeed > targetLeftSpeed) currentLeftSpeed = targetLeftSpeed;
  } else if (targetLeftSpeed < currentLeftSpeed) {
    currentLeftSpeed -= DECEL_STEP;
    if (currentLeftSpeed < targetLeftSpeed) currentLeftSpeed = targetLeftSpeed;
  }
}

void rotateMotor(int rightMotorSpeed, int leftMotorSpeed) {
  applyAcceleration(rightMotorSpeed, leftMotorSpeed);
  
  int combinedSpeed = (currentRightSpeed + currentLeftSpeed) / 2;
  
  digitalWrite(MOTOR_STBY, HIGH);
  
  if (combinedSpeed < 0) {
    digitalWrite(MOTOR_AIN1, LOW);
    digitalWrite(MOTOR_AIN2, HIGH);
  } else if (combinedSpeed > 0) {
    digitalWrite(MOTOR_AIN1, HIGH);
    digitalWrite(MOTOR_AIN2, LOW);
  } else {
    digitalWrite(MOTOR_AIN1, LOW);
    digitalWrite(MOTOR_AIN2, LOW);
  }
  
  int pwmValue = abs(combinedSpeed);
  if (pwmValue > 0 && pwmValue < MIN_MOTOR_SPEED) {
    pwmValue = MIN_MOTOR_SPEED;
  }
  ledcWrite(motorPWMSpeedChannel, pwmValue);
}

void stopMotors() {
  rotateMotor(0, 0);
}

void driveForward(int speed) {
  rotateMotor(speed, speed);
}

void turnLeft(int speed) {
  rotateMotor(speed, -speed);
}

void turnRight(int speed) {
  rotateMotor(-speed, speed);
}

void driveBackward(int speed) {
  rotateMotor(-speed, -speed);
}

// Sensor Reading
float readDistance() {
  float distance = sonar.ping_cm();
  if (distance == 0) distance = 200;
  return distance;
}

bool readIRSensor() {
  return digitalRead(IR_DO) == LOW;
}

float checkLeftDistance() {
  turnLeft(currentSpeed / 2);
  delay(200);
  float distance = readDistance();
  stopMotors();
  delay(50);
  return distance;
}

float checkRightDistance() {
  turnRight(currentSpeed / 2);
  delay(200);
  float distance = readDistance();
  stopMotors();
  delay(50);
  return distance;
}

// Autonomous Driving
void autonomousDrive() {
  float distance = readDistance();
  bool irObstacle = readIRSensor();
  
  if (distance < CRITICAL_DISTANCE || irObstacle) {
    stopMotors();
    delay(200);
    
    driveBackward(currentSpeed / 2);
    delay(300);
    stopMotors();
    delay(100);
    
    float leftDistance = checkLeftDistance();
    float rightDistance = checkRightDistance();
    
    if (leftDistance > rightDistance && leftDistance > OBSTACLE_DISTANCE) {
      turnLeft(currentSpeed);
      delay(TURN_DURATION);
    } else if (rightDistance > OBSTACLE_DISTANCE) {
      turnRight(currentSpeed);
      delay(TURN_DURATION);
    } else {
      driveBackward(currentSpeed / 2);
      delay(500);
      turnRight(currentSpeed);
      delay(TURN_DURATION * 2);
    }
    return;
  }
  
  if (distance < SAFE_DISTANCE && distance >= OBSTACLE_DISTANCE) {
    int reducedSpeed = map(distance, OBSTACLE_DISTANCE, SAFE_DISTANCE, 
                          currentSpeed / 3, currentSpeed);
    driveForward(reducedSpeed);
    return;
  }
  
  if (distance < OBSTACLE_DISTANCE) {
    stopMotors();
    delay(100);
    
    float leftDistance = checkLeftDistance();
    float rightDistance = checkRightDistance();
    
    if (leftDistance > rightDistance && leftDistance > OBSTACLE_DISTANCE) {
      turnLeft(currentSpeed);
      delay(TURN_DURATION);
    } else if (rightDistance > OBSTACLE_DISTANCE) {
      turnRight(currentSpeed);
      delay(TURN_DURATION);
    } else {
      driveBackward(currentSpeed / 2);
      delay(400);
      turnRight(currentSpeed);
      delay(TURN_DURATION * 1.5);
    }
    return;
  }
  
  driveForward(currentSpeed);
}

void setup() {
  Serial.begin(115200);
  delay(1000);
  
  Serial.println("========================================");
  Serial.println("  AUTONOMOUS DRIVING MODE");
  Serial.println("========================================");
  Serial.println();
  
  pinMode(MOTOR_AIN1, OUTPUT);
  pinMode(MOTOR_AIN2, OUTPUT);
  pinMode(MOTOR_PWMA, OUTPUT);
  pinMode(MOTOR_STBY, OUTPUT);
  digitalWrite(MOTOR_STBY, HIGH);
  digitalWrite(MOTOR_AIN1, LOW);
  digitalWrite(MOTOR_AIN2, LOW);
  
  ledcSetup(motorPWMSpeedChannel, PWMFreq, PWMResolution);
  ledcAttachPin(MOTOR_PWMA, motorPWMSpeedChannel);
  
  pinMode(IR_DO, INPUT);
  pinMode(IR_AO, INPUT);
  
  Serial.println("Autonomous driving initialized");
  Serial.print("Speed: ");
  Serial.println(currentSpeed);
  Serial.println();
  Serial.println("Commands:");
  Serial.println("  L - Low speed");
  Serial.println("  M - Medium speed (default)");
  Serial.println("  H - High speed");
  Serial.println("  S - Stop");
  Serial.println();
  Serial.println("Starting autonomous driving in 2 seconds...");
  delay(2000);
  
  Serial.println("GO!");
}

void loop() {
  if (Serial.available()) {
    char cmd = Serial.read();
    
    switch (cmd) {
      case 'L':
      case 'l':
        currentSpeed = SPEED_LOW;
        Serial.println("Speed: LOW");
        break;
        
      case 'M':
      case 'm':
        currentSpeed = SPEED_MEDIUM;
        Serial.println("Speed: MEDIUM");
        break;
        
      case 'H':
      case 'h':
        currentSpeed = SPEED_HIGH;
        Serial.println("Speed: HIGH");
        break;
        
      case 'S':
      case 's':
        stopMotors();
        Serial.println("STOPPED");
        break;
        
      case 'G':
      case 'g':
        driveForward(currentSpeed);
        Serial.println("Resuming...");
        break;
        
      default:
        break;
    }
    
    while (Serial.available()) Serial.read();
  }
  
  autonomousDrive();
  
  delay(10);
}

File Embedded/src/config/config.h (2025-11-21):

/*
 * Configuration Header File
 * 
 * IMPORTANT: This file is generated from .env file
 * To update: Run 'python scripts/generate_config.py' from project root
 * Or manually edit the values below
 * 
 * DO NOT commit sensitive data to version control
 */

#ifndef CONFIG_H
#define CONFIG_H

// ========== WiFi Configuration ==========
#define WIFI_SSID "YOUR_WIFI_SSID"
#define WIFI_PASSWORD "YOUR_WIFI_PASSWORD"

// ========== Server Configuration ==========
#define SERVER_IP "192.168.1.100"
#define SERVER_PORT 5000

// ========== Motor Speed Levels (PWM 0-255) ==========
#define MOTOR_SPEED_LOW 85
#define MOTOR_SPEED_MEDIUM 170
#define MOTOR_SPEED_HIGH 255

// ========== Obstacle Detection ==========
#define OBSTACLE_DISTANCE_CM 30
#define TURN_DURATION_MS 500

// ========== Sensor Reading Interval (milliseconds) ==========
#define SENSOR_READ_INTERVAL_MS 200

// ========== TFT Update Interval (milliseconds) ==========
#define TFT_UPDATE_INTERVAL_MS 500

#endif // CONFIG_H

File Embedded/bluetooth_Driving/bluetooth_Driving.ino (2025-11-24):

/*
 * Bluetooth Controlled Driving - Standalone Version
 * 
 * This is a minimal implementation for Bluetooth control of the car.
 * No autonomous driving, no data logging, no WiFi.
 * Just manual control via Bluetooth commands.
 * 
 * Usage:
 * 1. Upload this to ESP32
 * 2. Connect via Bluetooth (default name: "ESP32_Car")
 * 3. Send commands: F/B/L/R/S (Forward/Backward/Left/Right/Stop)
 * 4. Speed control: 1/2/3 (Low/Medium/High)
 */

#include <Arduino.h>
#include "BluetoothSerial.h"

#if !defined(CONFIG_BT_ENABLED) || !defined(CONFIG_BLUEDROID_ENABLED)
#error "Bluetooth is not enabled! Please run `make menuconfig` to enable it"
#endif

BluetoothSerial SerialBT;

// Motor Control
#define MOTOR_STBY 27
#define MOTOR_PWMA 25
#define MOTOR_AIN1 26
#define MOTOR_AIN2 13

// Speed Levels
#define SPEED_LOW 85
#define SPEED_MEDIUM 170
#define SPEED_HIGH 255

#define MIN_MOTOR_SPEED 50
const int PWMFreq = 20000;
const int PWMResolution = 8;
const int motorPWMSpeedChannel = 4;

int currentSpeed = SPEED_MEDIUM;
int currentRightSpeed = 0;
int currentLeftSpeed = 0;

// Motor Control Functions
void applyAcceleration(int targetRightSpeed, int targetLeftSpeed) {
  const int ACCEL_STEP = 5;
  const int DECEL_STEP = 8;
  
  if (targetRightSpeed > currentRightSpeed) {
    currentRightSpeed += ACCEL_STEP;
    if (currentRightSpeed > targetRightSpeed) currentRightSpeed = targetRightSpeed;
  } else if (targetRightSpeed < currentRightSpeed) {
    currentRightSpeed -= DECEL_STEP;
    if (currentRightSpeed < targetRightSpeed) currentRightSpeed = targetRightSpeed;
  }
  
  if (targetLeftSpeed > currentLeftSpeed) {
    currentLeftSpeed += ACCEL_STEP;
    if (currentLeftSpeed > targetLeftSpeed) currentLeftSpeed = targetLeftSpeed;
  } else if (targetLeftSpeed < currentLeftSpeed) {
    currentLeftSpeed -= DECEL_STEP;
    if (currentLeftSpeed < targetLeftSpeed) currentLeftSpeed = targetLeftSpeed;
  }
}

void rotateMotor(int rightMotorSpeed, int leftMotorSpeed) {
  applyAcceleration(rightMotorSpeed, leftMotorSpeed);
  
  int combinedSpeed = (currentRightSpeed + currentLeftSpeed) / 2;
  
  digitalWrite(MOTOR_STBY, HIGH);
  
  if (combinedSpeed < 0) {
    digitalWrite(MOTOR_AIN1, LOW);
    digitalWrite(MOTOR_AIN2, HIGH);
  } else if (combinedSpeed > 0) {
    digitalWrite(MOTOR_AIN1, HIGH);
    digitalWrite(MOTOR_AIN2, LOW);
  } else {
    digitalWrite(MOTOR_AIN1, LOW);
    digitalWrite(MOTOR_AIN2, LOW);
  }
  
  int pwmValue = abs(combinedSpeed);
  if (pwmValue > 0 && pwmValue < MIN_MOTOR_SPEED) {
    pwmValue = MIN_MOTOR_SPEED;
  }
  ledcWrite(motorPWMSpeedChannel, pwmValue);
}

void stopMotors() {
  rotateMotor(0, 0);
}

void driveForward(int speed) {
  rotateMotor(speed, speed);
}

void turnLeft(int speed) {
  rotateMotor(speed, -speed);
}

void turnRight(int speed) {
  rotateMotor(-speed, speed);
}

void driveBackward(int speed) {
  rotateMotor(-speed, -speed);
}

void setup() {
  Serial.begin(115200);
  delay(1000);
  
  Serial.println("========================================");
  Serial.println("  BLUETOOTH CONTROLLED DRIVING");
  Serial.println("========================================");
  Serial.println();
  
  // Initialize motor pins
  pinMode(MOTOR_AIN1, OUTPUT);
  pinMode(MOTOR_AIN2, OUTPUT);
  pinMode(MOTOR_PWMA, OUTPUT);
  pinMode(MOTOR_STBY, OUTPUT);
  digitalWrite(MOTOR_STBY, HIGH);
  digitalWrite(MOTOR_AIN1, LOW);
  digitalWrite(MOTOR_AIN2, LOW);
  
  // Setup PWM
  ledcSetup(motorPWMSpeedChannel, PWMFreq, PWMResolution);
  ledcAttachPin(MOTOR_PWMA, motorPWMSpeedChannel);
  
  // Initialize Bluetooth
  SerialBT.begin("ESP32_Car");
  Serial.println("Bluetooth initialized");
  Serial.println("Device name: ESP32_Car");
  Serial.println();
  Serial.println("Commands:");
  Serial.println("  F - Forward");
  Serial.println("  B - Backward");
  Serial.println("  L - Turn Left");
  Serial.println("  R - Turn Right");
  Serial.println("  S - Stop");
  Serial.println("  1 - Low speed");
  Serial.println("  2 - Medium speed");
  Serial.println("  3 - High speed");
  Serial.println();
  Serial.println("Waiting for Bluetooth connection...");
}

void loop() {
  // Check Bluetooth commands
  if (SerialBT.available()) {
    char cmd = SerialBT.read();
    Serial.print("Received: ");
    Serial.println(cmd);
    
    switch (cmd) {
      case 'F':
      case 'f':
        driveForward(currentSpeed);
        SerialBT.println("Forward");
        Serial.println("Forward");
        break;
        
      case 'B':
      case 'b':
        driveBackward(currentSpeed);
        SerialBT.println("Backward");
        Serial.println("Backward");
        break;
        
      case 'L':
      case 'l':
        turnLeft(currentSpeed);
        SerialBT.println("Turn Left");
        Serial.println("Turn Left");
        break;
        
      case 'R':
      case 'r':
        turnRight(currentSpeed);
        SerialBT.println("Turn Right");
        Serial.println("Turn Right");
        break;
        
      case 'S':
      case 's':
        stopMotors();
        SerialBT.println("Stop");
        Serial.println("Stop");
        break;
        
      case '1':
        currentSpeed = SPEED_LOW;
        SerialBT.println("Speed: LOW");
        Serial.println("Speed: LOW");
        break;
        
      case '2':
        currentSpeed = SPEED_MEDIUM;
        SerialBT.println("Speed: MEDIUM");
        Serial.println("Speed: MEDIUM");
        break;
        
      case '3':
        currentSpeed = SPEED_HIGH;
        SerialBT.println("Speed: HIGH");
        Serial.println("Speed: HIGH");
        break;
        
      default:
        SerialBT.println("Unknown command");
        Serial.println("Unknown command");
        break;
    }
  }
  
  // Also check Serial for debugging
  if (Serial.available()) {
    char cmd = Serial.read();
    
    switch (cmd) {
      case 'F':
      case 'f':
        driveForward(currentSpeed);
        Serial.println("Forward");
        break;
        
      case 'B':
      case 'b':
        driveBackward(currentSpeed);
        Serial.println("Backward");
        break;
        
      case 'L':
      case 'l':
        turnLeft(currentSpeed);
        Serial.println("Turn Left");
        break;
        
      case 'R':
      case 'r':
        turnRight(currentSpeed);
        Serial.println("Turn Right");
        break;
        
      case 'S':
      case 's':
        stopMotors();
        Serial.println("Stop");
        break;
        
      case '1':
        currentSpeed = SPEED_LOW;
        Serial.println("Speed: LOW");
        break;
        
      case '2':
        currentSpeed = SPEED_MEDIUM;
        Serial.println("Speed: MEDIUM");
        break;
        
      case '3':
        currentSpeed = SPEED_HIGH;
        Serial.println("Speed: HIGH");
        break;
        
      default:
        break;
    }
    
    while (Serial.available()) Serial.read();
  }
  
  delay(10);
}

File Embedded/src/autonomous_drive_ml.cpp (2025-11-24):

/*
 * ML-Enhanced Autonomous Driving
 * 
 * This file shows how to integrate ML predictions into autonomous driving.
 * The ML model predicts performance level (1-10) based on sensor features,
 * and the car adjusts its behavior accordingly.
 */

#include "autonomous_drive.h"
#include "ml_predictor.h"
#include "ESP32_car.h"
#include "config/config.h"

// Server URL for ML predictions
const char* ML_SERVER_URL = "Server_API";  // Update with your server IP

// ML prediction state
static MLPrediction lastPrediction;
static unsigned long lastMLUpdate = 0;
static const unsigned long ML_UPDATE_INTERVAL = 2000;  // Update every 2 seconds

// Speed adjustment based on ML prediction
static int baseSpeed = 80;  // Base speed (0-255)
static int currentMLAdjustedSpeed = baseSpeed;

/**
 * Get ML prediction and adjust speed accordingly
 * This is called periodically to update behavior based on predicted performance
 * 
 * NOTE: You need to implement readSensors() function that returns SensorData
 * with fields: voltage, current, temperature, accelX, accelY, accelZ, distance, speed
 */
void updateMLPrediction(SensorData sensorData) {
    unsigned long now = millis();
    
    // Only update prediction every ML_UPDATE_INTERVAL milliseconds
    if (now - lastMLUpdate < ML_UPDATE_INTERVAL) {
        return;
    }
    
    lastMLUpdate = now;
    
    // Get prediction from Python server
    lastPrediction = getMLPrediction(sensorData, ML_SERVER_URL);
    
    if (lastPrediction.success) {
        // Adjust speed based on predicted performance level (1-10)
        // Level 1 = very poor performance -> slow down
        // Level 10 = excellent performance -> can go faster
        
        int speedAdjustment = (lastPrediction.level - 5) * 10;  // -40 to +50
        currentMLAdjustedSpeed = baseSpeed + speedAdjustment;
        
        // Apply confidence penalty - if low confidence, be more cautious
        if (lastPrediction.confidence < 0.5) {
            currentMLAdjustedSpeed = (int)(currentMLAdjustedSpeed * 0.7);
        }
        
        // Clamp speed to safe range
        currentMLAdjustedSpeed = constrain(currentMLAdjustedSpeed, 30, 100);
        
        Serial.print("ML Level: ");
        Serial.print(lastPrediction.level);
        Serial.print(", Confidence: ");
        Serial.print(lastPrediction.confidence);
        Serial.print(", Adjusted Speed: ");
        Serial.println(currentMLAdjustedSpeed);
    } else {
        // If prediction fails, use base speed
        currentMLAdjustedSpeed = baseSpeed;
        Serial.print("ML prediction failed: ");
        Serial.println(lastPrediction.error_message);
    }
}

/**
 * ML-Enhanced Autonomous Drive
 * 
 * This function integrates ML predictions into the autonomous driving logic.
 * The car adjusts its speed and behavior based on predicted performance level.
 */
void autonomousDriveML() {
    // Use ML-adjusted speed for driving
    int driveSpeed = currentMLAdjustedSpeed;
    
    // Get obstacle distances (using existing functions from autonomous_drive)
    float frontDistance = readDistance();  // From autonomous_drive
    float leftDistance = checkLeftDistance();
    float rightDistance = checkRightDistance();
    
    // Note: To use ML predictions, you need to:
    // 1. Implement readSensors() function that returns SensorData
    // 2. Call updateMLPrediction(sensors) periodically
    // For now, we use the last prediction if available
    
    // Obstacle detection threshold - adjust based on ML prediction
    float obstacleThreshold = 20.0;  // cm
    
    // If performance is low, be more cautious (larger threshold)
    if (lastPrediction.success && lastPrediction.level < 4) {
        obstacleThreshold = 30.0;  // More cautious
    } else if (lastPrediction.success && lastPrediction.level > 7) {
        obstacleThreshold = 15.0;  // Can be more aggressive
    }
    
    // Emergency stop if too close
    if (frontDistance < 10.0) {
        emergencyStop();
        driveBackward(driveSpeed / 2);
        delay(500);
        return;
    }
    
    // Obstacle detected ahead
    if (frontDistance < obstacleThreshold) {
        // Check which side is clearer
        if (leftDistance > rightDistance && leftDistance > obstacleThreshold) {
            // Turn left - clearer path
            turnLeft(driveSpeed);
            delay(TURN_DURATION_MS);
        } else if (rightDistance > leftDistance && rightDistance > obstacleThreshold) {
            // Turn right - clearer path
            turnRight(driveSpeed);
            delay(TURN_DURATION_MS);
        } else {
            // Both sides blocked, back up
            driveBackward(driveSpeed / 2);
            delay(500);
            turnRight(driveSpeed);
            delay(TURN_DURATION_MS * 2);
        }
        return;
    }
    
    // No obstacle - drive forward at ML-adjusted speed
    driveForward(driveSpeed);
}

/**
 * Initialize ML-enhanced autonomous driving
 */
void initAutonomousDriveML() {
    // Initialize base autonomous drive
    initAutonomousDrive();
    
    // Check if ML model is available
    if (checkMLModelStatus(ML_SERVER_URL)) {
        Serial.println("✓ ML model is ready - using ML-enhanced driving");
    } else {
        Serial.println("⚠ ML model not available - using base autonomous drive");
    }
    
    // Initialize prediction
    lastPrediction.success = false;
    lastPrediction.level = 5;  // Default to middle level
    lastPrediction.confidence = 0.0;
}

/**
 * Get current ML-adjusted speed
 */
int getMLAdjustedSpeed() {
    return currentMLAdjustedSpeed;
}

/**
 * Get last ML prediction
 */
MLPrediction getLastMLPrediction() {
    return lastPrediction;
}

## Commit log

2025-11-21 modelling solidworks added
    [base_modelling_final.SLDPRT, base_modelling_intial.SLDPRT]
2025-11-21 Add sensor libraries and organize ESP32 code structure
2025-11-21 Add Bluetooth car control with TB6612FNG motor driver and variable speed/acceleration
2025-11-21 PlatformIO setup: Complete ESP32 development environment in Cursor
    - Added PlatformIO configuration (platformio.ini) with all sensor libraries
    - Converted autonomous_Driving.ino to PlatformIO structure (src/main.cpp)
    - Created VS Code tasks for build/upload/monitor
    - Added installation scripts for PlatformIO (Windows/Linux)
    - Created comprehensive setup documentation (PLATFORMIO_SETUP.md)
    - Added .env configuration system with example file
    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
2025-11-21 Fix TFT display and motor control, add MLP training with confusion matrix visualization
    [driving_behavior_dataset.csv]
2025-11-24 Add autonomous driving module, preprocessing pipeline, and cleanup batch files
    - Add autonomous_drive.cpp/h for modular autonomous driving system
    - Add preprocessing.py to process raw sensor data from data receiver
    - Add compile_and_upload_autonomous.bat for ESP32 deployment
    - Add run_model.bat for ML model training
    - Remove decorative comment separators (==== and -----)
    - Clean up unnecessary batch files
    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
2025-11-24 Clean up unnecessary files and add data API with security features
    - Remove redundant documentation files (STEP_BY_STEP_GUIDE, DATA_FLOW_EXPLANATION, etc.)
    - Add data API server (data_api.py) for querying SQLite database
    - Add security check script (check_security.py) and SECURITY.md guide
    - Update .gitignore to protect sensitive files (config.h, .env, databases)
    - Restore autonomous_Driving.ino and bluetooth_Driving.ino standalone sketches
    - Update README files to reflect current project structure
    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
    [driving_behavior_dataset.csv]
2025-11-24 Update TFT display to show real-time sensor data and comprehensive README
    - Modified TFT_LED.cpp to calculate RINT from actual voltage and current
    - Display performance level 0-10 with color-coded progress bar
    - Show real-time RINT, voltage, current, and temperature (no hardcoded values)
    - Updated function signatures to accept temperature parameter
    - Comprehensive README update with full project documentation
    - Removed PLATFORMIO_SETUP.md (redundant documentation)
